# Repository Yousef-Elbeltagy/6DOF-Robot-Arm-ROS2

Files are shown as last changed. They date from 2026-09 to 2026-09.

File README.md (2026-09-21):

<div align="center">

# 6DOF Robot Arm — ROS 2

### Mechanical design → actuator sizing → FEA → URDF → simulation → control → sequence programming → autonomous jig placement









**A 6-axis robot arm developed from SolidWorks CAD into a complete ROS 2 simulation, programming, and autonomous jig-placement system.**

**[Quick Start](QUICKSTART.md) · [Documentation](docs/README.md) · [CAD Files](cad/README.md) · [Roadmap](ROADMAP.md) · [Changelog](CHANGELOG.md)**

</div>

---

## Project at a glance

| | |
|---|---|
| **Robot** | 6-DOF articulated arm + custom gripper |
| **Design target** | ~1.5 m reach, ~10 kg payload |
| **Mechanical CAD** | SolidWorks native source + STEP interoperability exports |
| **Main structure** | 6061-T6 aluminum |
| **Robot model** | URDF + STL meshes |
| **Robotics stack** | ROS 2 Humble, MoveIt 2, RViz 2, ros2_control |
| **Simulation** | Gazebo Classic 11 |
| **Control application** | Custom Python/Tkinter GUI |
| **Programming** | Saved poses, PTP/LIN sequences, blending, digital I/O, gripper actions |
| **Autonomy** | Runtime IK, dynamic TF targets, full-table jig placement |
| **Public validation** | Environment check, clean public build, and full simulation launch verified |
| **Development context** | Robotics / Mechatronics internship project |

> The final system is a **simulation-validated engineering prototype**. The physical six-axis arm was not fully commissioned during the project period because the selected integrated joint modules had a long procurement lead time.

---

## Why this project exists

Wire-harness production can depend on dedicated boards and fixed jig layouts for each product or variant. That creates slow changeovers, storage overhead, and limited flexibility when layouts change.

The concept explored here is a reusable workboard with modular jigs. Instead of rebuilding a board, the robot selects the correct jig from a source table and places it at the required target position automatically.

The long-term vision is a flexible cell where a camera reads a harness layout, identifies placement targets, and the robot configures the board automatically.

---

# Development workflow

```text
1. Mechanical architecture & CAD
             ↓
2. Torque calculation & actuator selection
             ↓
3. FEA / stiffness / manufacturability
             ↓
4. CAD → URDF conversion
             ↓
5. Gazebo + MoveIt 2 + RViz validation
             ↓
6. ros2_control integration
             ↓
7. Custom operator interface
             ↓
8. Saved poses & sequence programming
             ↓
9. Automatic jig placement
             ↓
10. Full-table autonomous simulation
```

The README follows that same order below.

---

# 1. Mechanical Design

The project started as a full mechanical robot-arm design in SolidWorks. The early work focused on the overall 6-axis architecture, cylindrical links, joint interfaces, actuator packaging, gripper integration, manufacturability, and assembly feasibility.

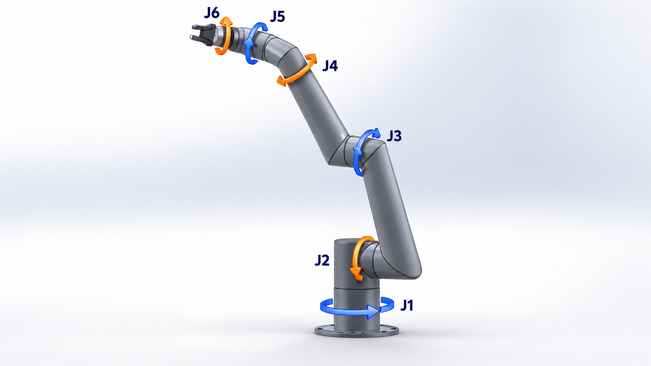
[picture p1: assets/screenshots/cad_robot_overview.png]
SolidWorks robot CAD


<table>
  <tr>
    <td align="center" width="50%">
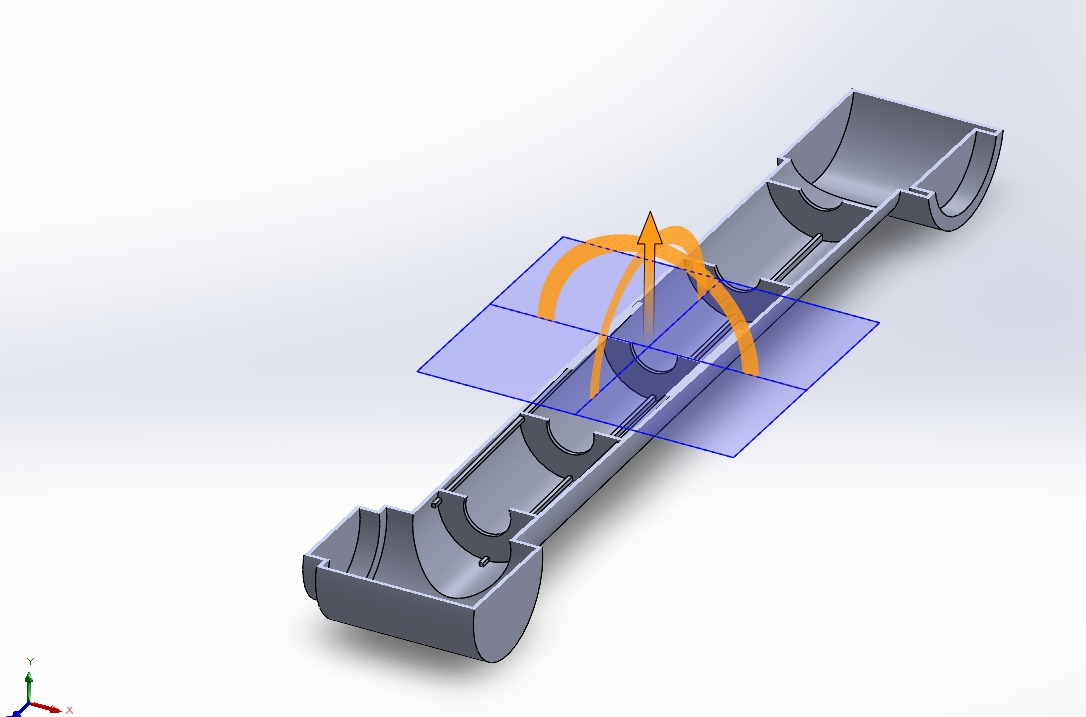
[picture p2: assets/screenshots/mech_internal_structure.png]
      <br>
      <sub><b>Early internal structural concept</b><br>Initial support/rib exploration and joint reference geometry.</sub>
    </td>
    <td align="center" width="50%">
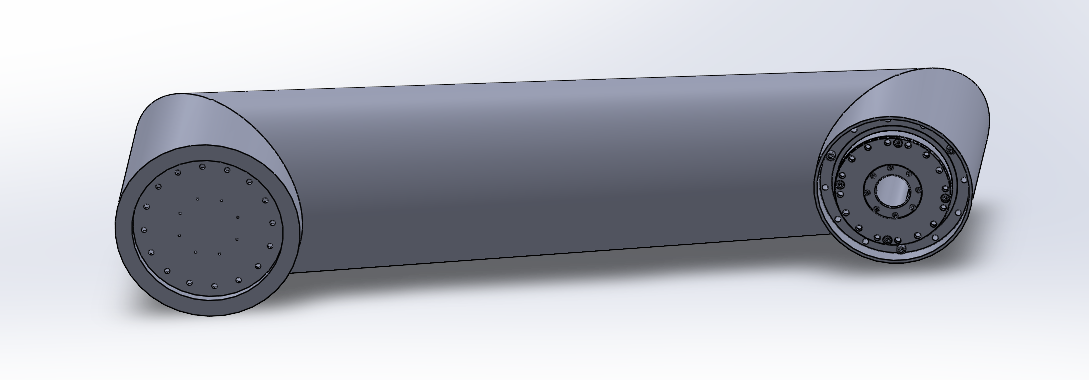
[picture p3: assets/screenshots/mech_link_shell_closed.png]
      <br>
      <sub><b>Cylindrical link shell</b><br>External link geometry and end-interface packaging.</sub>
    </td>
  </tr>
  <tr>
    <td align="center" width="50%">
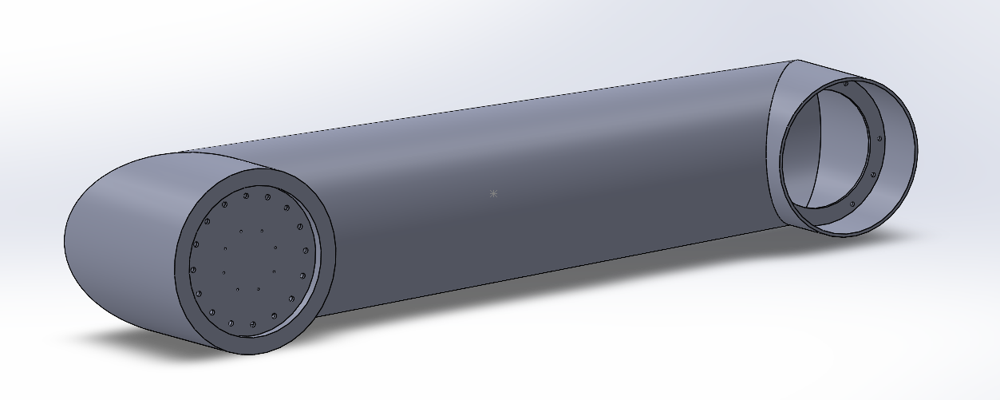
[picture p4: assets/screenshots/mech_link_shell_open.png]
      <br>
      <sub><b>Joint-side CAD view</b><br>Flange, mounting-hole, and actuator-interface development.</sub>
    </td>
    <td align="center" width="50%">
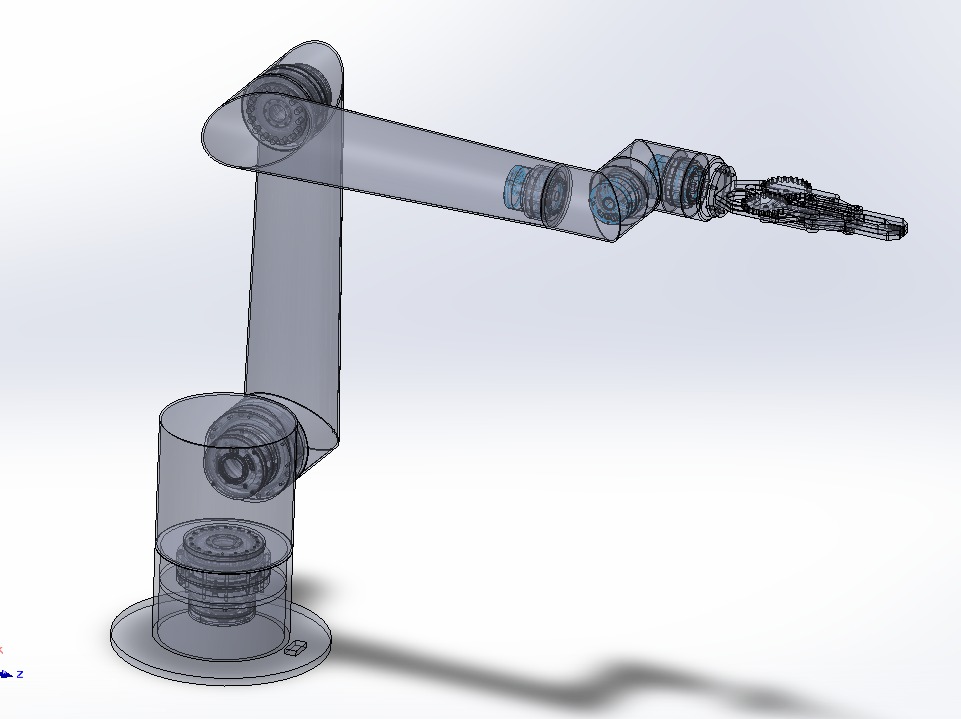
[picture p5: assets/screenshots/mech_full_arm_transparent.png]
      <br>
      <sub><b>Transparent full-arm assembly</b><br>Internal packaging of joints, drives, wrist, and gripper.</sub>
    </td>
  </tr>
</table>

### Mechanical evolution

- 6-DOF articulated architecture with cylindrical links.
- Hollow aluminum structure to reduce moving mass.
- Early internal-rib concepts were explored, then removed from the final manufacturing direction because of fabrication complexity.
- Final link strategy used simpler unribbed shells with wall thickness, geometry, local reinforcement, housings, and smooth transitions carrying the structural load.
- Custom cycloidal and planetary/belt reduction concepts were studied before integrated joint modules became the final actuator direction.

➡️ **[Mechanical design details](docs/MECHANICAL_DESIGN.md)**  
➡️ **[Native SolidWorks + STEP CAD packages](cad/README.md)**

---

# 2. Torque Calculation & Actuator Selection

The next step was determining the joint loads and selecting actuators capable of handling the arm, wrist, gripper, and payload.

### Dynamic joint torque results

| Joint | Peak torque |
|---|---:|
| J1 | 115.58 N·m |
| **J2** | **411.90 N·m** |
| J3 | 182.49 N·m |
| J4 | 35.64 N·m |
| J5 | 15.50 N·m |
| J6 | 5.10 N·m |

J2 became the governing axis because it carries the downstream links, wrist, gripper, and payload.

### Final integrated actuator concept

| Joint(s) | Module | Rated torque | Peak/start-stop torque |
|---|---|---:|---:|
| J1-J2 | TD-110-170 | 328 N·m | 702 N·m |
| J3 | TD-100-142 | 169 N·m | 411 N·m |
| J4-J6 | TD-70-90 | 50 N·m | 102 N·m |

The final concept used integrated servo/reducer modules rather than continuing with a custom gearbox for every joint. This reduced gearbox-development risk and simplified packaging around the major axes.

---

# 3. Structural Analysis & FEA

Strength alone was not enough; stiffness and local stress concentration also mattered because end-effector deflection directly affects positioning accuracy.

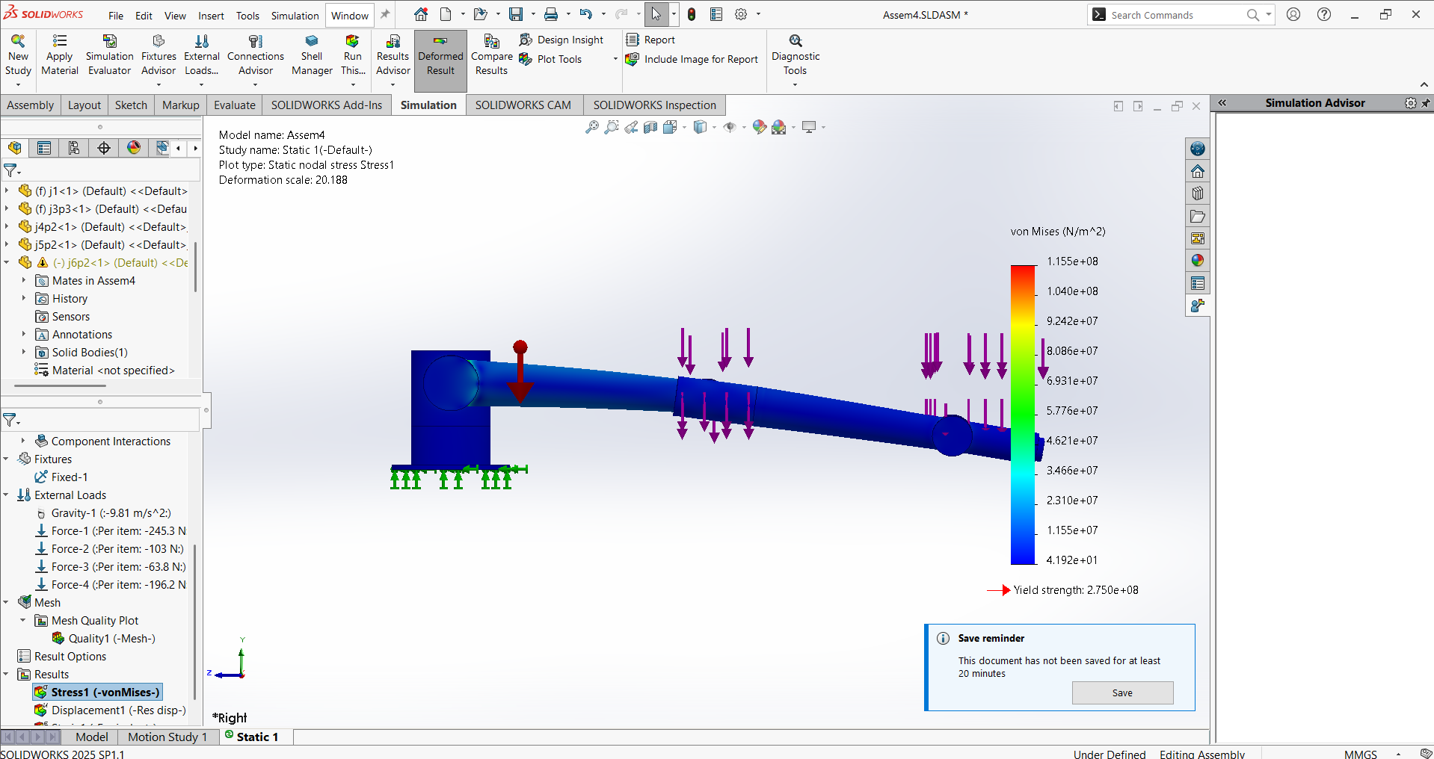
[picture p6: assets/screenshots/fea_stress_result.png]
FEA stress result


Important findings included:

- one representative study produced approximately **105 MPa** maximum stress against a 6061-T6 yield strength of approximately **275 MPa**, giving a factor of safety of about **2.6**,
- later local analysis around a J2 transition showed a much higher peak at a sharp geometric transition, identifying a stress-concentration problem rather than a uniformly overloaded link,
- global displacement studies showed that the robot could remain below yield while still being too flexible for accurate positioning,
- the long links and forearm became major stiffness drivers, leading to thickness and geometry iterations.

These results drove smoother transitions, local reinforcement, and a stronger focus on stiffness rather than only yield strength.

---

# 4. CAD → URDF → ROS 2

Once the mechanical model was stable enough, the SolidWorks assembly was prepared for ROS 2.

The export workflow included:

- parent/child link hierarchy,
- revolute joint axes,
- coordinate systems and joint origins,
- mass and center of mass,
- inertia tensors,
- motion limits,
- visual STL meshes,
- collision geometry,
- gripper mimic relationships.

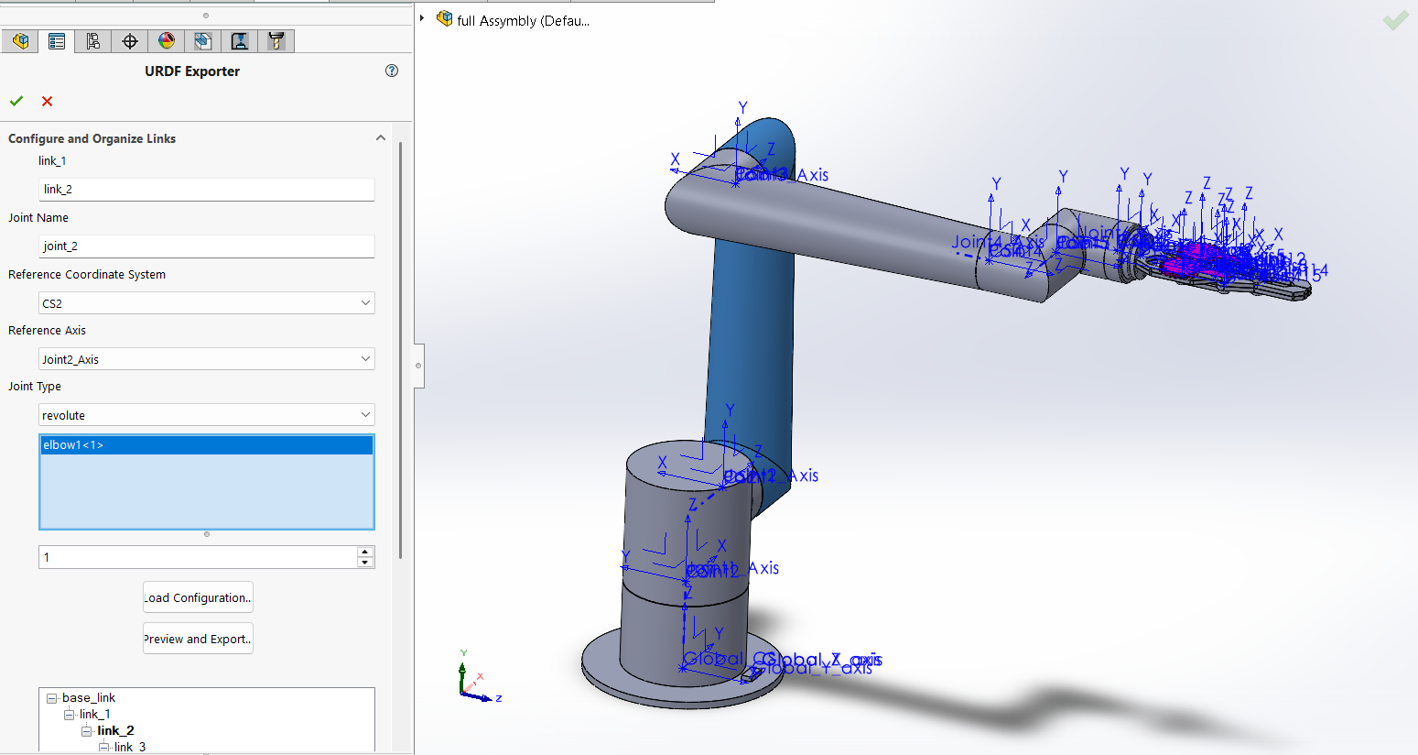
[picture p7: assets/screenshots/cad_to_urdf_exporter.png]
CAD to URDF exporter


The SolidWorks assembly pose became the zero/home reference for the URDF model, with joint names standardized as `joint_1` through `joint_6`.

---

# 5. Simulation & Motion Planning

The exported robot was then integrated into the ROS 2 simulation stack and validated before higher-level automation was added.

<table>
<tr>
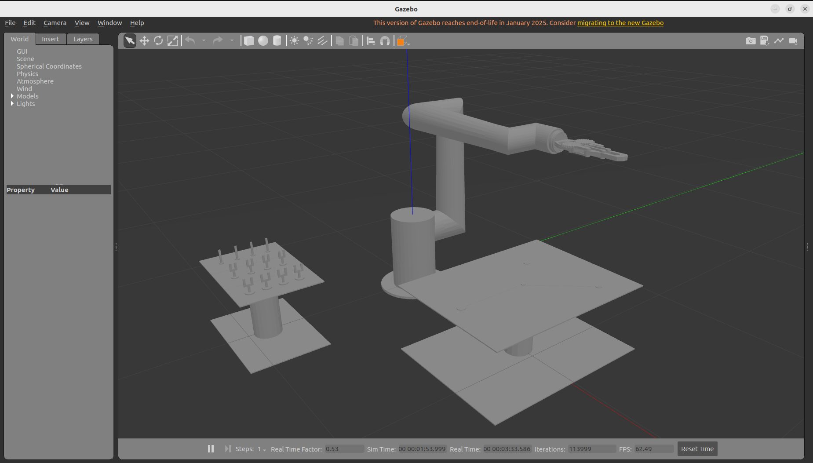
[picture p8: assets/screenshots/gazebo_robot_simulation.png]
Gazebo simulation
<td width="50%"></td>
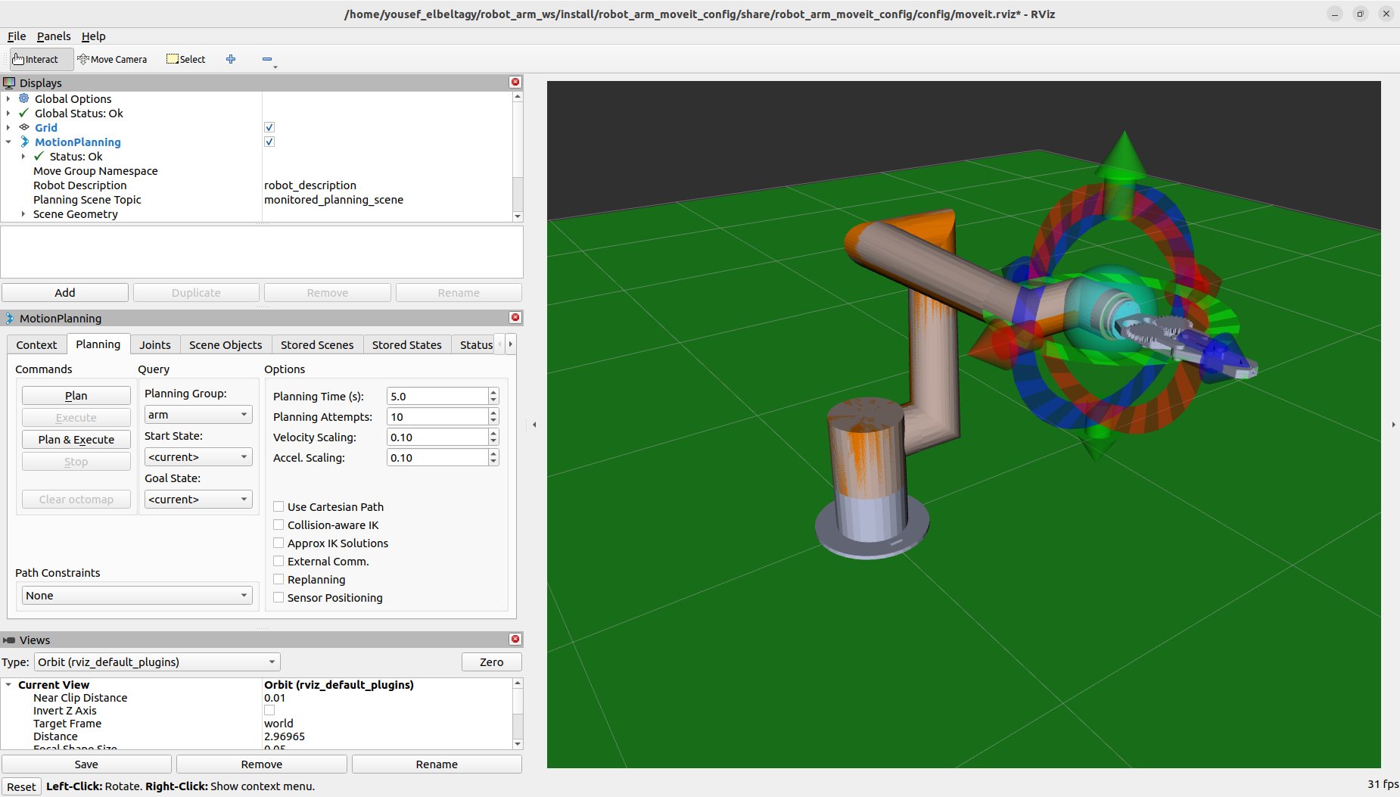
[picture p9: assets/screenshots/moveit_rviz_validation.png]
MoveIt RViz
<td width="50%"></td>
</tr>
<tr>
<td align="center"><b>Gazebo Classic 11</b></td>
<td align="center"><b>MoveIt 2 + RViz 2</b></td>
</tr>
</table>

### Simulation stack

| Layer | Technology |
|---|---|
| Operating system | Ubuntu 22.04 LTS |
| Middleware | ROS 2 Humble |
| Physics simulation | Gazebo Classic 11 |
| Motion planning | MoveIt 2 |
| Planning pipelines | OMPL + Pilz |
| Visualization | RViz 2 |
| Control | ros2_control + ros2_controllers |
| Build | colcon / ament |

MoveIt 2 handled IK, planning, collision checking, and trajectory generation. Gazebo provided the workcell physics and robot execution environment, while RViz was used to validate planning-scene and robot-state behavior.

➡️ **[Software architecture](docs/SOFTWARE_ARCHITECTURE.md)**

---

# 6. ros2_control & Robot Execution

The arm controller was integrated through `ros2_control` using trajectory actions for the six arm joints and a separate trajectory controller for the gripper.

Important execution interfaces include:

```text
/arm_controller/follow_joint_trajectory
/gripper_controller/follow_joint_trajectory
/sequence_move_group
```

This layer turned MoveIt plans into actual simulated robot motion and became the foundation for both the operator GUI and the later automatic placement system.

---

# 7. Main Operator Interface

After the robot could plan and execute reliably, a custom Python/Tkinter application was built around it.

<p align="center">
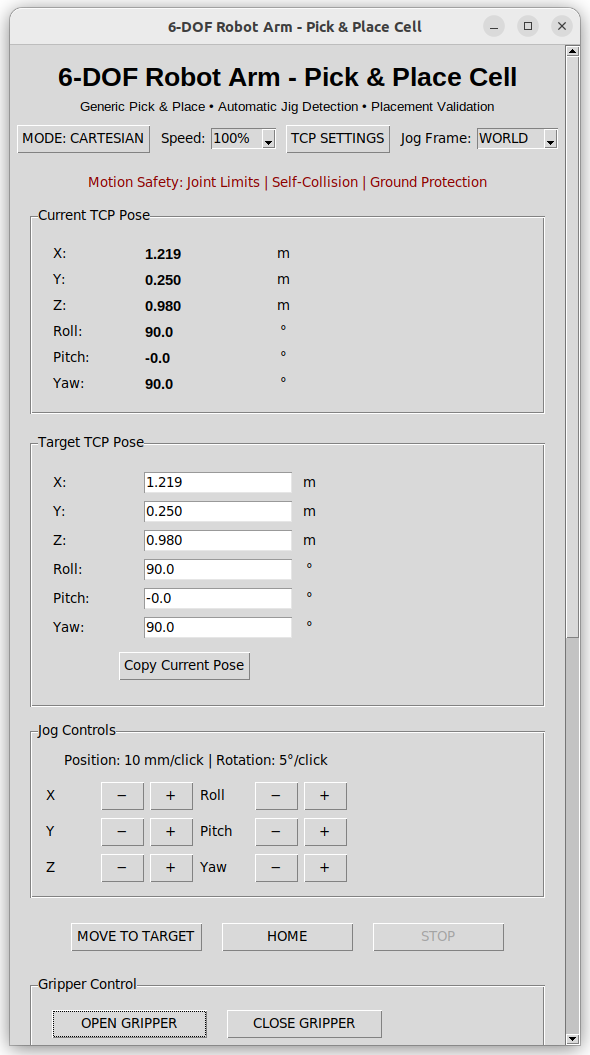
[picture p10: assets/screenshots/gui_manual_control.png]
Main Robot Control GUI
  
</p>

The interface provides:

- Cartesian X/Y/Z jogging,
- Roll/Pitch/Yaw jogging,
- joint jogging,
- speed override,
- WORLD / FLANGE / TOOL jog frames,
- configurable Tool Center Point,
- current and target TCP pose display,
- gripper open/close,
- six digital inputs,
- six digital outputs,
- saved robot poses,
- access to the Sequence Controller,
- access to Automatic Jig Placement,
- live application status.

This was the point where the project moved from a robotics stack controlled mainly through ROS tools into a usable operator-facing application.

---

# 8. Sequence Programming

The **Sequence Controller** was built after manual control and saved poses were working. It turns taught poses into ordered robot programs with motion behavior, process logic, I/O, and gripper synchronization.

<p align="center">
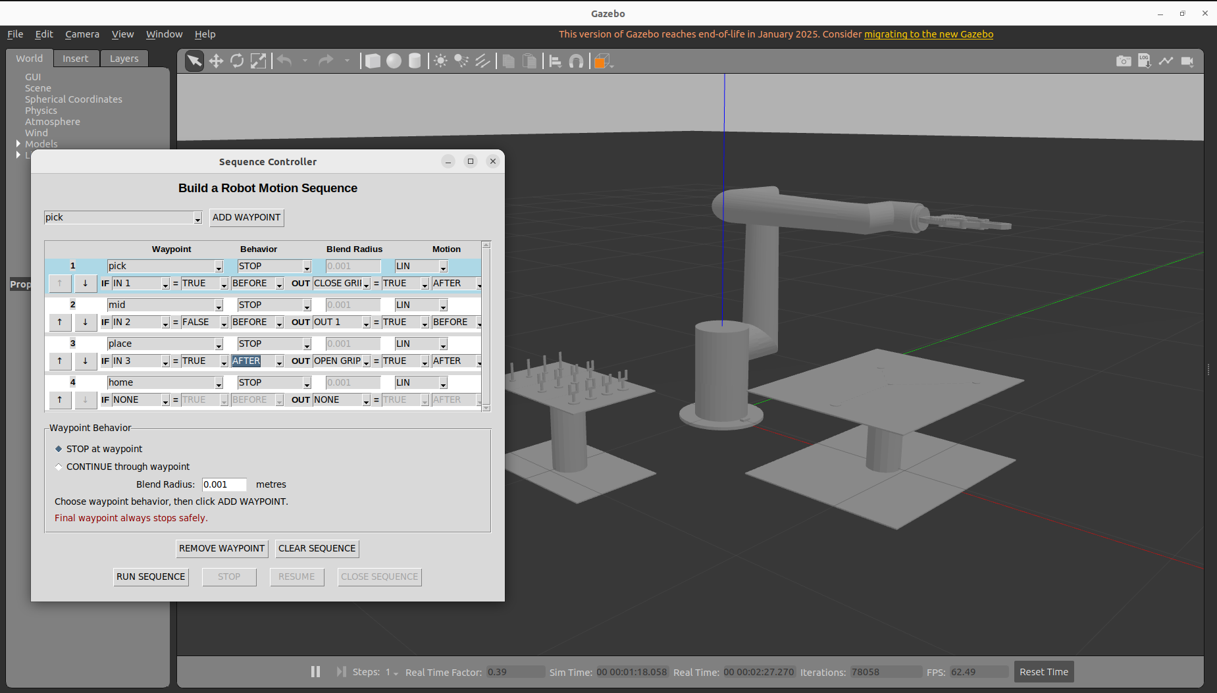
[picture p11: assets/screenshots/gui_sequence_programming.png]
Sequence Controller
  
</p>

Each program row can define:

| Sequence field | Options / behavior |
|---|---|
| **Waypoint** | Any saved robot pose |
| **Behavior** | `STOP` / `CONTINUE` |
| **Blend Radius** | Configurable transition radius |
| **Motion** | `PTP` / `LIN` |
| **Input Source** | `NONE`, `IN 1` … `IN 6` |
| **Input State** | `TRUE` / `FALSE` |
| **Input Timing** | `BEFORE` / `AFTER` |
| **Output Action** | `NONE`, `OUT 1` … `OUT 6`, `OPEN GRIPPER`, `CLOSE GRIPPER` |
| **Output State** | `TRUE` / `FALSE` where applicable |
| **Output Timing** | `BEFORE` / `AFTER` |

Example logic:

```text
IF IN 1 == TRUE BEFORE PICK → move → CLOSE GRIPPER AFTER
IF IN 2 == FALSE BEFORE MID → set OUT 1 = TRUE BEFORE
IF IN 3 == TRUE AFTER PLACE → OPEN GRIPPER AFTER
HOME → final safe stop
```

### Gripper synchronization

The arm is not allowed to continue while the gripper is still moving:

```text
arm motion segment
      ↓
stop at gripper waypoint
      ↓
send gripper FollowJointTrajectory goal
      ↓
wait for the real controller result
      ↓
continue next arm segment
```

### STOP / RESUME

STOP cancels both the active MoveIt sequence goal and the active arm-controller trajectory. RESUME retries the interrupted step from the robot's current state.

The sequence work also exposed and drove fixes for motion types being unintentionally forced to PTP, duplicate `move_group` processes, LIN/Pilz start-state constraints, stale gripper feedback, asynchronous action-result handling, and gripper synchronization.

➡️ **[Read the full Sequence Programming & Execution documentation](docs/SEQUENCE_PROGRAMMING.md)**

---

# 9. Automatic Jig Placement

The final major software layer was the autonomous jig-placement system. It combines target discovery, jig matching, runtime IK, robot motion, simulated grasping, placement validation, and repeatable full-table execution.

<p align="center">
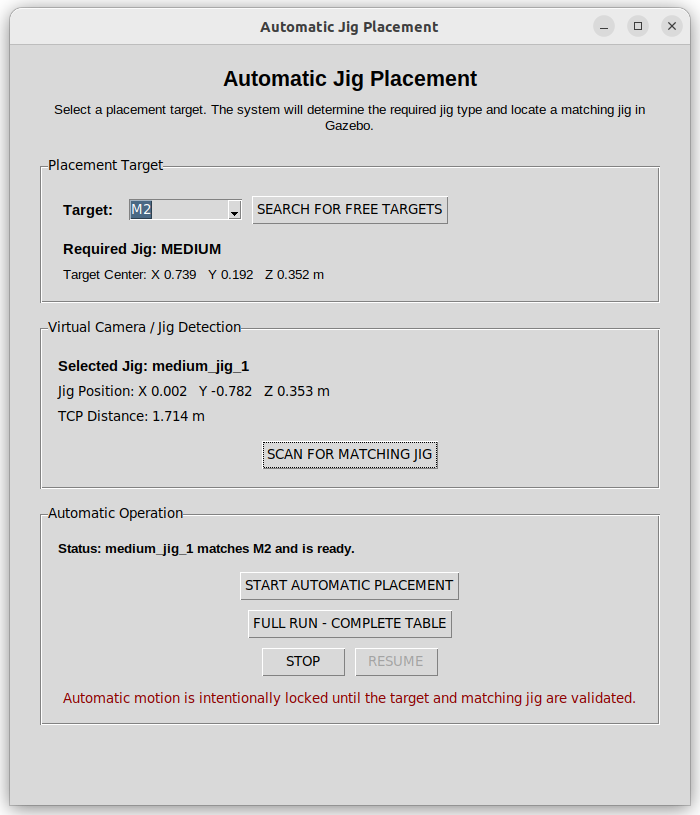
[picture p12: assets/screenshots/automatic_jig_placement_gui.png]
Automatic Jig Placement Interface
  
</p>

### Target discovery & jig matching

The interface discovers free target frames at runtime, identifies the required jig family, and searches for an unused matching jig.

```text
L1 → LARGE jig
M1 → MEDIUM jig
M2 → MEDIUM jig
S1 → SMALL jig
```

Targets are discovered from TF frame names ending in `_target_link` instead of relying only on a fixed list of coordinates.

### Runtime IK & branch selection

For each pickup and placement pose, the controller evaluates multiple IK candidates and chooses a practical branch from the current robot state:

```text
Target TCP pose
      ↓
Generate multiple IK seeds
      ↓
Call MoveIt IK
      ↓
Collect valid solutions
      ↓
Compare wrapped joint deltas
      ↓
Penalize excessive wrist motion
      ↓
Choose the lowest-motion candidate
      ↓
Execute through the PTP path
```

### Automatic execution

```text
Discover/select free target
        ↓
Infer required jig size
        ↓
Find unused matching jig
        ↓
Move above pickup
        ↓
Descend
        ↓
Close gripper + attach jig
        ↓
Lift and transfer
        ↓
Move above target
        ↓
Descend
        ↓
Open gripper + detach
        ↓
Validate placement
        ↓
Mark jig used + target occupied
        ↓
Retract and continue
```

The GUI supports both **single-placement execution** and **FULL RUN – COMPLETE TABLE**.

Two independent state trackers prevent incorrect repeated operations:

```python
placed_jig_models
filled_placement_targets
```

`placed_jig_models` prevents reuse of a jig that has already been placed. `filled_placement_targets` prevents a second jig from being sent to an occupied target.

### Stable simulated detach

Jig grasping is simulated with the IFRA LinkAttacher plugin. A difficult Gazebo stability bug was traced to detach operations being executed directly from a ROS service callback thread. The final design queues the request and performs `Joint::Detach()` from Gazebo's update thread instead.

### Immediate STOP / RESUME

STOP cancels the active MoveIt goal and active arm-controller trajectory during automatic motion. RESUME retries the interrupted automatic step from the current robot state.

### Demonstrated in simulation

- dynamic target discovery,
- automatic jig-size inference,
- unused-jig matching,
- runtime multi-seed IK,
- wrist-aware branch selection,
- simulated pickup and attachment,
- transfer and release,
- placement validation,
- jig inventory tracking,
- target occupancy tracking,
- single-target execution,
- full-table automatic execution,
- immediate STOP / RESUME.

➡️ **[Read the full Automatic Jig Placement documentation](docs/AUTOMATIC_JIG_PLACEMENT.md)**

---

# 10. Engineering Lessons & Debugging

Some of the most valuable work came from failures rather than first-pass successes:

- custom gearbox interference and manufacturability limitations,
- local stress concentrations,
- excessive structural deflection,
- duplicate MoveIt processes,
- sequence execution bugs,
- PTP/LIN handling issues,
- stale controller/GUI state,
- gripper synchronization timing,
- poor IK branches and wrist flips,
- reused-jig inventory bugs,
- Gazebo detach-thread crashes.

Each of these problems changed the design or software architecture rather than being hidden as a one-off workaround.

➡️ **[Read the engineering lessons](docs/ENGINEERING_LESSONS.md)**

---

## Repository structure

```text
6DOF-Robot-Arm-ROS2/
├── README.md
├── QUICKSTART.md
├── CHANGELOG.md
├── ROADMAP.md
├── LICENSE
├── NOTICE
├── CONTRIBUTING.md
├── src/                         # ROS 2 source packages
├── scripts/                     # dependency, build, validation and startup helpers
├── config/                      # TCP and saved-pose configuration
├── cad/
│   ├── README.md                # CAD package map and interoperability notes
│   ├── Solidworks_Cad_models/   # native SolidWorks archives
│   └── STEP_Exports/            # neutral STEP workcell/components archive
├── assets/
│   └── screenshots/             # real CAD, simulation and GUI screenshots
└── docs/                        # engineering, setup and continuation documentation
```

---

## Getting started

The validated public baseline is **Ubuntu 22.04 + ROS 2 Humble**. The repository itself is the workspace and already contains `src/`.

```bash
cd ~
git clone https://github.com/Yousef-Elbeltagy/6DOF-Robot-Arm-ROS2.git robot_arm_ws
cd ~/robot_arm_ws

bash scripts/setup_dependencies.sh
bash scripts/build_workspace.sh

cp config/robot_arm_saved_poses.json ~/robot_arm_saved_poses.json
cp config/robot_arm_tcp_config.json ~/robot_arm_tcp_config.json

bash scripts/check_system.sh
bash scripts/start_robot.sh
```

➡️ **[Quick Start](QUICKSTART.md)**  
➡️ **[Full reproduction guide](docs/REPRODUCE_PROJECT.md)**

---

## Documentation

| Document | What it covers |
|---|---|
| [Quick Start](QUICKSTART.md) | Shortest validated path from clone to launch |
| [Documentation Index](docs/README.md) | Map of all engineering and reproduction docs |
| [Reproduce Project](docs/REPRODUCE_PROJECT.md) | Clean-machine reproduction workflow |
| [Project Story](docs/PROJECT_STORY.md) | Evolution from manufacturing problem to autonomous workcell |
| [Mechanical Design](docs/MECHANICAL_DESIGN.md) | Structure, materials, torque, reducers, actuators, FEA |
| [CAD Packages](cad/README.md) | Native SolidWorks archives and STEP interoperability exports |
| [Software Architecture](docs/SOFTWARE_ARCHITECTURE.md) | ROS 2, URDF, MoveIt, Gazebo, ros2_control, GUI |
| [Sequence Programming](docs/SEQUENCE_PROGRAMMING.md) | Waypoints, PTP/LIN, blending, I/O, gripper barriers, STOP/RESUME |
| [Automatic Jig Placement](docs/AUTOMATIC_JIG_PLACEMENT.md) | Dynamic targets, runtime IK, full run, inventory and placement logic |
| [Engineering Lessons](docs/ENGINEERING_LESSONS.md) | Problems encountered and how they changed the system |
| [Results](docs/RESULTS.md) | Demonstrated capabilities and project status |
| [Gallery](docs/GALLERY.md) | Real project screenshots |
| [Setup](docs/SETUP.md) | Detailed ROS 2 environment setup |
| [Troubleshooting](docs/TROUBLESHOOTING.md) | Build/runtime diagnosis |
| [Continue Development](docs/CONTINUE_DEVELOPMENT.md) | Safe continuation path for future developers |
| [Roadmap](ROADMAP.md) | Physical integration, vision, calibration, safety and commissioning |
| [Changelog](CHANGELOG.md) | Major public repository milestones |

---

## Current status & roadmap

### Completed / validated in simulation

- [x] 6-DOF robot CAD
- [x] torque calculation and actuator selection
- [x] structural FEA / stiffness studies
- [x] gripper CAD and URDF
- [x] Gazebo simulation
- [x] MoveIt 2 planning
- [x] RViz validation
- [x] ros2_control integration
- [x] custom Python GUI
- [x] saved poses
- [x] multi-waypoint sequence programming
- [x] STOP / CONTINUE waypoint behavior
- [x] blend radius
- [x] PTP / LIN sequence selection
- [x] digital I/O sequence logic
- [x] synchronized gripper sequence actions
- [x] runtime IK
- [x] dynamic target discovery
- [x] autonomous single placement
- [x] full-table automatic execution
- [x] immediate automatic STOP / RESUME
- [x] native SolidWorks CAD publication
- [x] neutral STEP workcell/component exports
- [x] public repository environment check
- [x] public repository build validation
- [x] public Gazebo / MoveIt / RViz / GUI launch validation

### Future work

- [ ] physical actuator integration
- [ ] EtherCAT / CAN hardware interface
- [ ] real robot calibration
- [ ] camera-based target recognition
- [ ] automatic workplane calibration
- [ ] hand-guided teaching
- [ ] physical payload/stiffness validation
- [ ] industrial electrical and safety architecture
- [ ] complete cell commissioning

➡️ **[Detailed roadmap](ROADMAP.md)**

---

## Internship context & authorship

This repository documents the robot design, ROS 2 stack, simulation, control GUI, sequence-programming system, and automatic-placement engineering work developed during a broader internship project.

The internship project involved a team and supervision; this repository focuses on the technical robotics work represented here and is presented as an educational/portfolio reference rather than as a claim that every part of the wider internship project was completed by one person.

---

## Author

**Yousef El-Beltagy**  
Robotics & Mechatronics

---

<div align="center">

### CAD. ANALYZE. SIMULATE. PLAN. PROGRAM. CONTROL. AUTOMATE.

</div>

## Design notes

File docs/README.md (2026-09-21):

# Documentation Index

Use this page as the map for the project documentation.

## Start here

| Goal | Document |
|---|---|
| Get the project running quickly | [../QUICKSTART.md](../QUICKSTART.md) |
| Reproduce the project from a clean machine | [REPRODUCE_PROJECT.md](REPRODUCE_PROJECT.md) |
| Continue development from the current state | [CONTINUE_DEVELOPMENT.md](CONTINUE_DEVELOPMENT.md) |
| Diagnose runtime/build problems | [TROUBLESHOOTING.md](TROUBLESHOOTING.md) |
| Inspect native/neutral CAD | [../cad/README.md](../cad/README.md) |
| See planned next engineering phases | [../ROADMAP.md](../ROADMAP.md) |
| Review public project milestones | [../CHANGELOG.md](../CHANGELOG.md) |
| Contribute changes | [../CONTRIBUTING.md](../CONTRIBUTING.md) |

## Engineering documentation

| Topic | Document |
|---|---|
| Project evolution | [PROJECT_STORY.md](PROJECT_STORY.md) |
| Mechanical design | [MECHANICAL_DESIGN.md](MECHANICAL_DESIGN.md) |
| Major components / actuator BOM | [BOM.md](BOM.md) |
| ROS 2 / MoveIt / Gazebo architecture | [SOFTWARE_ARCHITECTURE.md](SOFTWARE_ARCHITECTURE.md) |
| Sequence Controller | [SEQUENCE_PROGRAMMING.md](SEQUENCE_PROGRAMMING.md) |
| Automatic jig placement | [AUTOMATIC_JIG_PLACEMENT.md](AUTOMATIC_JIG_PLACEMENT.md) |
| Engineering lessons | [ENGINEERING_LESSONS.md](ENGINEERING_LESSONS.md) |
| Demonstrated results and current status | [RESULTS.md](RESULTS.md) |
| Screenshots | [GALLERY.md](GALLERY.md) |
| Setup details | [SETUP.md](SETUP.md) |

## Mechanical source packages

The `cad/` directory contains:

- native SolidWorks archives for the robot/gripper, jigs, and workcell tables,
- a neutral STEP archive containing the complete workcell and separate component STEP exports.

See [../cad/README.md](../cad/README.md) before modifying or redistributing mechanical source files.

## Recommended reading order for a new developer

```text
QUICKSTART
    ↓
REPRODUCE_PROJECT
    ↓
SOFTWARE_ARCHITECTURE
    ↓
SEQUENCE_PROGRAMMING
    ↓
AUTOMATIC_JIG_PLACEMENT
    ↓
CONTINUE_DEVELOPMENT
    ↓
TROUBLESHOOTING as needed
```

For mechanical continuation, also read `MECHANICAL_DESIGN.md`, `BOM.md`, and `../cad/README.md` before changing link geometry or actuator selection.

## Status language

The public repository represents a **simulation-validated engineering prototype**. Do not describe the project as a fully commissioned or certified industrial/collaborative robot unless future physical testing and safety validation support that claim.

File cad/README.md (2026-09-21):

# CAD Models

This directory contains the mechanical CAD packages used for the 6-DOF robot-arm project, including both the original SolidWorks files and neutral STEP exports for interoperability.

## Available CAD archives

| Archive | Contents | Approx. size |
|---|---|---:|
| `Solidworks_Cad_models/full_Cobot_Solidworks_Cad.zip` | Full 6-DOF robot arm and gripper SolidWorks CAD package | 32.7 MB |
| `Solidworks_Cad_models/Cobot_Jigs_Solidworks_Cad.zip` | Jig CAD models used by the automatic placement workcell | 0.9 MB |
| `Solidworks_Cad_models/Pick_Table_Solidworks_Cad.zip` | Pick/placement table and target-related SolidWorks CAD package | 1.2 MB |
| `STEP_Exports/Complete_Robot_Workcell_STEP_Components.zip` | Neutral STEP export package containing the complete robot workcell assembly together with separate STEP component files | 22.0 MB |

## Which format should I use?

Use the **SolidWorks archives** when you want the original editable design files and native assembly relationships.

Use the **STEP export archive** when you want to inspect, measure, reuse, or import the geometry in another CAD package without requiring SolidWorks.

The STEP archive contains:

- the complete robot/workcell STEP assembly,
- the 6-DOF robot and gripper geometry,
- workcell table geometry,
- target and jig geometry,
- separate STEP files for the exported assembly components.

## Relationship to the ROS 2 model

The CAD models are the mechanical source geometry behind the robot and workcell that were later converted into ROS 2 / Gazebo assets.

The corresponding software models are located under `src/`, including:

- `robot_arm_with_gripper_urdf`
- `table_harness_urdf_v3`
- `pick_table_urdf`
- `large_jig_urdf`
- `medium_jig_urdf`
- `small_jig_urdf`

The robot assembly was prepared in SolidWorks with joint axes, reference geometry, mass properties, and link relationships before export to URDF and STL meshes for ROS 2.

## Mechanical design status

The published CAD represents the engineering prototype developed during the project. The system was validated extensively in simulation, but the complete physical six-axis robot was not fully commissioned during the project period because the selected integrated actuator modules had a long procurement lead time.

Important mechanical design notes:

- 6-DOF articulated robot architecture
- approximately 1.5 m design reach
- approximately 10 kg payload design target
- 6061-T6 aluminum as the main structural material
- integrated servo/reducer joint modules selected as the final actuator direction
- early internal-rib concepts were investigated, but the final manufacturing direction used simpler unribbed cylindrical shells with local reinforcement and appropriate wall thickness
- custom gripper integrated into the final robot assembly

## Opening the files

### SolidWorks

Extract the relevant ZIP archive before opening its assemblies or parts. Keep all referenced files from an archive together after extraction so SolidWorks can resolve assembly references correctly.

### STEP

Extract `STEP_Exports/Complete_Robot_Workcell_STEP_Components.zip`, then open either the complete workcell STEP assembly or the individual component STEP files in any CAD package with STEP support.

## Notes for contributors

Please do not commit SolidWorks temporary/lock files such as `~$*` or backup files. Large handover archives, private company documents, supplier quotations, and internal project backups are intentionally excluded from this public repository.

For the mechanical design background, see [`../docs/MECHANICAL_DESIGN.md`](../docs/MECHANICAL_DESIGN.md).

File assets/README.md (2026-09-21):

# Screenshot Assets

These images were extracted from the project's own presentation material and originate from real project screenshots/CAD/simulation captures supplied during development.

They are intended for the public GitHub project page.

Included:
- SolidWorks robot CAD
- CAD/URDF exporter view
- FEA result
- Gazebo robot simulation
- MoveIt/RViz validation
- Python GUI/manual-control walkthrough
- Sequence programming walkthrough
- Automatic jig-placement GUI workflow

No image-generation artwork is included in this folder.

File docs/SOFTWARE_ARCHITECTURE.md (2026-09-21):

# Software Architecture

The project combines a CAD-derived robot model with ROS 2 motion planning, physics simulation, trajectory control and a custom operator interface.

## Platform

```text
Ubuntu 22.04 LTS
ROS 2 Humble
Gazebo Classic 11
MoveIt 2
RViz 2
ros2_control
ros2_controllers
OMPL
Pilz Industrial Motion Planner
Python 3 / Tkinter
```

## Data flow

```text
SolidWorks CAD
      ↓
URDF + STL meshes
      ↓
ROS 2 robot description
      ↓
+-----------------------------+
|                             |
↓                             ↓
Gazebo Classic             MoveIt 2
physics / joints           planning / IK
|                             |
+-------------+---------------+
              ↓
          ros2_control
              ↓
      trajectory controllers
              ↓
      custom Python GUI
```

## Main ROS packages

The development workspace contains packages for the robot, workcell and application logic, including:

```text
robot_arm_with_gripper_urdf
robot_arm_moveit_config
robot_arm_python
pymoveit2
table_harness_urdf_v3
pick_table_urdf
large_jig_urdf
medium_jig_urdf
small_jig_urdf
IFRA_LinkAttacher
```

## URDF model

The robot model contains six revolute arm joints plus the full gripper hierarchy.

The CAD-to-URDF workflow preserves:

- parent/child link hierarchy
- joint origin and axis
- joint limits
- mass
- center of mass
- inertia tensor
- visual meshes
- collision meshes
- gripper mimic relationships

## MoveIt 2

MoveIt is used for:

- inverse kinematics
- collision-aware planning
- joint-limit checking
- trajectory generation
- planning scene visualization
- sequence execution

The main planning group is:

```text
arm
```

The project uses OMPL and Pilz planning pipelines. PTP is the known-good motion mode used by the automatic placement workflow.

## ros2_control

The simulated arm is controlled through a FollowJointTrajectory controller for J1-J6, with a separate trajectory controller for the gripper.

Important actions include:

```text
/arm_controller/follow_joint_trajectory
/gripper_controller/follow_joint_trajectory
/sequence_move_group
```

## Custom operator GUI

The Python/Tkinter controller evolved into a full robot operator interface.

It supports:

- Cartesian X/Y/Z jogging
- Roll/Pitch/Yaw jogging
- J1-J6 joint jogging
- speed override
- WORLD / FLANGE / TOOL jog frames
- TCP configuration
- saved poses
- HOME
- STOP / RESUME
- gripper open/close
- sequence programming
- PTP / LIN row selection
- STOP / CONTINUE waypoint behavior
- blend radius
- digital I/O
- automatic jig placement

## Tool Center Point

The working TCP used by the controller is approximately:

```text
[0, 0, 0.4193463143, 0, 0, 0]
```

This is intentionally different from the shorter `link_6 -> gripper_base` transform. The GUI performs the TCP/flange conversion mathematically when generating motion targets.

## Sequence controller

The sequence system is designed to feel closer to an industrial robot programming workflow than a basic list of poses.

Each row can contain:

- saved waypoint
- STOP / CONTINUE behavior
- blend radius
- PTP / LIN selection
- digital input condition
- digital output action
- gripper actions

Gripper actions act as execution barriers: arm motion stops, the gripper trajectory completes, and only then does the next arm segment begin.

## Immediate STOP / RESUME

A major behavior improvement was making STOP interrupt an active automatic movement rather than waiting for the current trajectory to finish.

The implementation cancels both the MoveIt sequence goal and the active arm-controller trajectory. RESUME then retries the interrupted automatic step from the robot's current state.

## Gazebo grasping

The simulated pick-and-place uses IFRA LinkAttacher services to attach and detach jig models.

A native Gazebo crash was traced to detach operations being performed from the ROS service callback thread. The plugin was modified so that detach requests are queued and the actual `Joint::Detach()` occurs inside Gazebo's update thread.

This was one of the most important simulation-stability fixes in the project.

## Development philosophy

The project was debugged using an evidence-first workflow:

1. reproduce the failure
2. inspect ROS/Gazebo logs
3. isolate the failing layer
4. change one behavior at a time
5. rebuild
6. cold-restart when runtime state matters
7. create checkpoints after stable milestones

That workflow was especially important because failures could originate from the GUI, MoveIt, controller timing, TF, Gazebo physics or plugin threading.

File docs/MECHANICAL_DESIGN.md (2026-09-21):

# Mechanical Design

This project started as a mechanical robot-arm design problem before it became a ROS 2 software project.

## Design target

The main concept was a 6-axis articulated arm for a flexible wire-harness manufacturing cell.

- Target reach: approximately **1.5 m**
- Target payload: approximately **10 kg**
- Architecture: 6 revolute joints
- Main structural material: **Aluminum 6061-T6**
- Manufacturing goal: geometry that could realistically be produced and assembled

## Joint architecture

| Joint | Main role |
|---|---|
| J1 | Base rotation |
| J2 | Shoulder elevation |
| J3 | Elbow positioning |
| J4 | Wrist orientation |
| J5 | Wrist orientation |
| J6 | Tool/flange orientation |

J2 became the governing mechanical joint because it carries the payload together with the mass of the downstream links, wrist, gripper and actuators.

## Link design evolution

The arm went through several iterations. Early designs explored thicker cylindrical shells and internal ribs. Later iterations moved toward lighter hollow links, with wall thickness and local joint-housing geometry carrying the structural load.

The final manufacturing direction avoided internal ribs after fabrication feedback showed that the ribbed concept would be unnecessarily difficult to manufacture.

Instead, stiffness improvements were focused on:

- increasing local wall thickness where needed
- larger diameters where practical
- smoother transitions between links and joint housings
- larger fillets at high-stress transitions
- stronger local actuator mounting regions

## Material selection

6061-T6 aluminum was selected for the main moving links because of its combination of:

- low density
- good strength-to-weight ratio
- corrosion resistance
- machinability
- practical availability

Other materials considered during development included 7075-T6, stainless steel and alloy steels for localized high-stress parts such as shafts and pins.

## Torque model

The final dynamic peak torque values used in the engineering presentation were approximately:

| Joint | Dynamic peak torque |
|---|---:|
| J1 | 115.58 N·m |
| J2 | **411.90 N·m** |
| J3 | 182.49 N·m |
| J4 | 35.64 N·m |
| J5 | 15.50 N·m |
| J6 | 5.10 N·m |

This made J2 the governing axis for actuator sizing.

## Gearbox research

Several drivetrain concepts were investigated before the final actuator selection.

### Custom cycloidal reducers

A custom cycloidal gearbox was explored because precision robot reducers were difficult to source locally.

The work included:

- single- and multi-stage ratio studies
- dual cycloidal discs
- eccentric shaft design
- roller/pin geometry
- interference checking
- bearing-pocket sizing
- material selection and heat-treatment considerations

The concept was ultimately not selected because the machining precision, backlash control, heat treatment and development schedule created too much project risk.

### Planetary + timing belt

A planetary gearbox with optional timing-belt pre-reduction was also studied. This provided more realistic local manufacturability but still added packaging and compliance complexity.

### Final integrated joint modules

The final concept moved to integrated robotic joint modules containing the motor, encoder, brake and reducer in one unit.

| Joints | Module | Rated torque | Peak/start-stop torque |
|---|---|---:|---:|
| J1-J2 | TD-110-170 | 328 N·m | 702 N·m |
| J3 | TD-100-142 | 169 N·m | 411 N·m |
| J4-J6 | TD-70-90 | 50 N·m | 102 N·m |

This dramatically simplified the mechanical integration compared with designing six custom reducer assemblies.

## FEA lessons

Structural analysis showed two distinct engineering challenges:

1. **Local stress concentration** around joint transitions, especially near J2.
2. **Global deflection** of the long links.

One study showed a high local peak around the J2 transition, while stress dropped substantially a short distance away. That indicated a geometry-driven stress concentration rather than uniform tube failure.

Another displacement study showed end-effector deflection on the order of a few centimetres under the assumed loading case, indicating that stiffness was a more important issue than simply increasing material strength.

The main design lessons were therefore:

- do not optimize only for yield stress
- examine displacement and stiffness at the TCP
- use smooth load paths
- avoid sharp housing transitions
- increase local thickness only where it improves the load path

## CAD-to-robot-model workflow

SolidWorks was used to define:

- link geometry
- joint axes
- reference coordinate systems
- mass properties
- centers of mass
- inertias
- visual/collision meshes

These definitions were then carried into the URDF model used by ROS 2, Gazebo and MoveIt.

## Status

The mechanical design reached a simulation-ready and actuator-integrated CAD stage. The complete physical robot was not commissioned during the internship/project period because the selected integrated joint modules had a long procurement lead time.

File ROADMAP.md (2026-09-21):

# Roadmap

The current repository is a **simulation-validated engineering prototype**. This roadmap separates demonstrated software capability from future physical-system work.

## Current validated baseline

- 6-DOF robot and custom gripper CAD
- torque sizing and actuator selection
- structural FEA and stiffness studies
- URDF / STL model generation
- Gazebo Classic 11 simulation
- MoveIt 2 + RViz planning and validation
- ros2_control arm and gripper execution
- manual Cartesian and joint jogging
- saved poses and TCP handling
- industrial-style sequence programming
- synchronized gripper actions
- digital I/O logic
- PTP / LIN sequence selection
- runtime IK with multi-seed branch selection
- dynamic target discovery
- automatic jig pickup and placement
- placement and inventory validation
- full-table automatic execution
- immediate STOP / RESUME
- native SolidWorks CAD archives
- neutral STEP workcell/component exports
- clean public build and launch validation on Ubuntu 22.04 / ROS 2 Humble

## Next engineering phase

### 1. Physical actuator integration

- install the selected integrated joint modules,
- define final mechanical mounting and cable routing,
- validate brake behavior,
- map real joint feedback and commands into ros2_control,
- implement repeatable startup and shutdown procedures.

Tracked in GitHub issue #1.

### 2. Industrial communication

- integrate EtherCAT and/or CAN interfaces supported by the selected actuators,
- define hardware abstraction and fault handling,
- validate command rate, feedback timing, and emergency-stop behavior.

### 3. Robot calibration

- establish joint-zero references,
- calibrate kinematic parameters,
- validate TCP position/orientation,
- characterize backlash, repeatability, and payload-dependent deflection.

### 4. Vision and automatic workplane setup

- select and calibrate a camera,
- detect workboard / harness-layout targets,
- estimate the workplane pose,
- transform detected targets into the robot frame,
- feed approved targets into the existing automatic-placement pipeline.

Tracked in GitHub issue #2.

### 5. Physical performance validation

- payload testing,
- structural-deflection measurements,
- repeatability testing,
- cycle-time measurement,
- long-duration reliability testing.

### 6. Industrial safety and commissioning

- electrical architecture,
- safety-rated stop design,
- guarding / collaborative-operation assessment,
- risk assessment,
- production commissioning.

## Reproduction quality

A clean-machine reproduction test remains useful for confirming that no implicit development-machine dependency is missing from the public instructions. See GitHub issue #3.

## Mechanical-source completeness

Native SolidWorks archives and neutral STEP exports are now included. Further additions should be limited to genuinely useful manufacturing drawings or updated revisions rather than historical CAD backups. See GitHub issue #4 for the original CAD-publication task.

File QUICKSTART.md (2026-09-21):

# Quick Start

For the complete walkthrough, use [docs/REPRODUCE_PROJECT.md](docs/REPRODUCE_PROJECT.md). This page is the shortest validated path from a clean Ubuntu 22.04 machine to the simulated robot.

## Supported baseline

```text
Ubuntu 22.04 LTS
ROS 2 Humble
Gazebo Classic 11
MoveIt 2
RViz 2
ros2_control / ros2_controllers
Python 3 / Tkinter
colcon / ament
```

## 1. Clone the repository as the workspace

The repository already contains its ROS packages under `src/`, so clone the repository itself as `~/robot_arm_ws`:

```bash
cd ~
git clone https://github.com/Yousef-Elbeltagy/6DOF-Robot-Arm-ROS2.git robot_arm_ws
cd ~/robot_arm_ws
```

Do **not** clone the whole repository into `~/robot_arm_ws/src`; that would create a nested `src/src` layout.

## 2. Install dependencies

After installing ROS 2 Humble, Gazebo Classic, MoveIt 2, ros2_control, and the development tools listed in [docs/REPRODUCE_PROJECT.md](docs/REPRODUCE_PROJECT.md), run:

```bash
cd ~/robot_arm_ws
bash scripts/setup_dependencies.sh
```

## 3. Build

```bash
cd ~/robot_arm_ws
bash scripts/build_workspace.sh
```

A successful build should finish all project packages without errors.

## 4. Restore GUI configuration

The GUI reads the saved-pose and TCP configuration from the user's home directory:

```bash
cp ~/robot_arm_ws/config/robot_arm_saved_poses.json ~/robot_arm_saved_poses.json
cp ~/robot_arm_ws/config/robot_arm_tcp_config.json ~/robot_arm_tcp_config.json
```

## 5. Verify the environment

```bash
cd ~/robot_arm_ws
bash scripts/check_system.sh
```

The validated project machine reported all checks passing before the public launch test.

## 6. Start the complete simulation

```bash
cd ~/robot_arm_ws
bash scripts/start_robot.sh
```

The launcher brings up Gazebo Classic, MoveIt 2, RViz 2, the arm and gripper controllers, and the custom robot GUI.

## 7. First checks after launch

Verify that:

- the robot appears correctly in Gazebo and RViz,
- `/move_group` is running,
- the arm and gripper controllers are active,
- the GUI opens and reports a connected robot,
- small jogs and gripper commands execute correctly.

Then test a saved pose, a short Sequence Controller program, and the Automatic Jig Placement interface.

## Where to go next

- Full reproduction guide: [docs/REPRODUCE_PROJECT.md](docs/REPRODUCE_PROJECT.md)
- Setup details: [docs/SETUP.md](docs/SETUP.md)
- Continue development: [docs/CONTINUE_DEVELOPMENT.md](docs/CONTINUE_DEVELOPMENT.md)
- Troubleshooting: [docs/TROUBLESHOOTING.md](docs/TROUBLESHOOTING.md)
- Software architecture: [docs/SOFTWARE_ARCHITECTURE.md](docs/SOFTWARE_ARCHITECTURE.md)
- Sequence programming: [docs/SEQUENCE_PROGRAMMING.md](docs/SEQUENCE_PROGRAMMING.md)
- Automatic jig placement: [docs/AUTOMATIC_JIG_PLACEMENT.md](docs/AUTOMATIC_JIG_PLACEMENT.md)
- Native and neutral CAD: [cad/README.md](cad/README.md)
- Contributing: [CONTRIBUTING.md](CONTRIBUTING.md)

## Project status

This repository reproduces the **simulation-validated engineering prototype**. Physical actuator integration, calibration, machine safety, certification, and production commissioning remain future work.

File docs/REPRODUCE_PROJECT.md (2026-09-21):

# Reproduce the Project

This guide is for someone who wants to clone the repository, build the ROS 2 workspace, launch the simulation, and reach the same software baseline used during development.

## Supported baseline

- Ubuntu 22.04 LTS
- ROS 2 Humble
- Gazebo Classic 11
- MoveIt 2
- RViz 2
- ros2_control / ros2_controllers
- OMPL
- Pilz Industrial Motion Planner
- Python 3 + Tkinter
- colcon / ament

The project was developed against Gazebo Classic rather than modern Gz Sim.

## 1. Install ROS 2 and development tools

Follow the official ROS 2 Humble installation procedure for Ubuntu 22.04, then install the main packages:

```bash
sudo apt update
sudo apt install -y \
  ros-humble-desktop \
  build-essential \
  cmake \
  git \
  python3-pip \
  python3-tk \
  python3-yaml \
  python3-rosdep \
  python3-colcon-common-extensions \
  python3-vcstool \
  ros-humble-ros2-control \
  ros-humble-ros2-controllers \
  gazebo \
  ros-humble-gazebo-ros-pkgs \
  ros-humble-gazebo-ros2-control \
  ros-humble-moveit \
  ros-humble-moveit-planners-ompl \
  ros-humble-pilz-industrial-motion-planner
```

Initialize rosdep if needed:

```bash
sudo rosdep init
rosdep update
```

If `rosdep init` reports that it was already initialized, continue with `rosdep update`.

## 2. Clone the repository as the workspace

The repository root already contains `src/`, `scripts/`, `config/`, and the project documentation. Clone the repository itself as the workspace:

```bash
cd ~
git clone https://github.com/Yousef-Elbeltagy/6DOF-Robot-Arm-ROS2.git robot_arm_ws
cd ~/robot_arm_ws
```

The resulting layout should look like:

```text
~/robot_arm_ws/
├── src/
├── scripts/
├── config/
├── docs/
└── README.md
```

Do not clone the complete repository inside `~/robot_arm_ws/src`, because that creates a nested `src/src` layout and breaks the documented helper-script paths.

## 3. Install package dependencies

Recommended:

```bash
cd ~/robot_arm_ws
bash scripts/setup_dependencies.sh
```

Equivalent rosdep command:

```bash
source /opt/ros/humble/setup.bash
cd ~/robot_arm_ws
rosdep install --from-paths src --ignore-src -r -y --rosdistro humble
```

`warehouse_ros_mongo` is intentionally not required by this repository. It is optional MoveIt warehouse functionality and is not needed for the normal planning, simulation, sequence, or jig-placement workflows documented here.

## 4. Build

Recommended:

```bash
cd ~/robot_arm_ws
bash scripts/build_workspace.sh
```

Equivalent manual build:

```bash
cd ~/robot_arm_ws
source /opt/ros/humble/setup.bash
colcon build --symlink-install
source install/setup.bash
```

The public repository has been validated by building all project packages from its own `src/` tree.

## 5. Restore runtime configuration

The GUI expects these files in the user's home directory:

```text
~/robot_arm_saved_poses.json
~/robot_arm_tcp_config.json
```

Copy the repository versions:

```bash
cp ~/robot_arm_ws/config/robot_arm_saved_poses.json ~/robot_arm_saved_poses.json
cp ~/robot_arm_ws/config/robot_arm_tcp_config.json ~/robot_arm_tcp_config.json
```

The validated TCP translation is approximately:

```text
[0, 0, 0.4193463143]
```

Do not replace that value with the shorter `link_6 -> gripper_base` offset; they represent different things.

## 6. Check the environment

Run:

```bash
cd ~/robot_arm_ws
bash scripts/check_system.sh
```

Fix any reported missing dependency before launching the full system. On the validated development machine, the public environment check completed with all checks passing.

## 7. Launch the project

The convenience launcher starts Gazebo, waits for both arm and gripper controllers, starts MoveIt, opens RViz, then launches the Tkinter GUI:

```bash
cd ~/robot_arm_ws
bash scripts/start_robot.sh
```

Expected major components:

```text
Gazebo Classic
MoveIt / move_group
RViz 2
arm_controller
gripper_controller
Robot GUI
```

The public repository was also launch-tested after a clean build: Gazebo, MoveIt, RViz, the GUI, robot model, and controllers all started correctly.

## 8. Verify a successful launch

Controllers:

```bash
ros2 control list_controllers
```

Expected active controllers include the six-axis arm trajectory controller and the gripper trajectory controller.

MoveIt:

```bash
ros2 node list | grep move_group
```

There should normally be one active `/move_group` instance.

Sequence action:

```bash
ros2 action info /sequence_move_group
```

Arm trajectory action:

```bash
ros2 action info /arm_controller/follow_joint_trajectory
```

Gripper trajectory action:

```bash
ros2 action info /gripper_controller/follow_joint_trajectory
```

## 9. First functional test

Use the GUI in this order:

1. Confirm the status reports that the robot is connected.
2. Test a very small Cartesian jog.
3. Test gripper open / close.
4. Load one saved pose and move to it.
5. Open the Sequence Controller and run a short two-waypoint sequence.
6. Open Automatic Jig Placement, search for a free target, scan for a matching jig, and validate the displayed target/jig information before starting motion.

## 10. Repository packages

Important packages include:

```text
robot_arm_with_gripper_urdf
robot_arm_moveit_config
robot_arm_python
pymoveit2
table_harness_urdf_v3
pick_table_urdf
large_jig_urdf
medium_jig_urdf
small_jig_urdf
IFRA_LinkAttacher
```

## 11. Mechanical source files

The public `cad/` directory contains both native SolidWorks archives and neutral STEP exports. See [../cad/README.md](../cad/README.md) for the CAD package map and interoperability notes.

## 12. What is reproduced

This repository reproduces the simulation and control prototype, including:

- six-axis robot + gripper URDF,
- Gazebo workcell,
- MoveIt planning,
- ros2_control execution,
- manual GUI control,
- saved poses,
- sequence programming,
- digital I/O logic,
- runtime IK,
- automatic jig selection and placement,
- simulated attach/detach,
- full-table automation logic.

It does not reproduce a commissioned physical industrial robot. Hardware integration, calibration, safety engineering, certification, and production commissioning remain future work.

## 13. If something fails

See [TROUBLESHOOTING.md](TROUBLESHOOTING.md) before changing coordinates, IK logic, controller timing, or attach/detach behavior.

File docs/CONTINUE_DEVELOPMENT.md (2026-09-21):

# Continue Development

This document is for the next developer who wants to continue the project from the current simulation-validated state rather than reconstructing its history from commits.

## Current validated state

The repository contains a working ROS 2 Humble simulation/control stack for a 6-DOF arm with gripper and a wire-harness jig-placement workcell.

Validated in simulation:

- 6-DOF arm URDF and meshes
- gripper integration
- Gazebo Classic workcell
- ros2_control arm and gripper trajectory execution
- MoveIt 2 planning
- RViz validation
- Cartesian and joint jogging
- saved robot poses
- configurable TCP
- sequence programming
- STOP / CONTINUE waypoint behavior
- blend radius
- PTP / LIN selection
- digital input/output logic
- synchronized gripper actions
- runtime IK
- dynamic placement-target discovery
- unused-jig inventory tracking
- target occupancy tracking
- single automatic placement
- full-table automatic execution
- immediate STOP / RESUME

## Important files

```text
src/robot_arm_python/robot_arm_python/robot_gui.py
    Main GUI, manual control, sequence logic, runtime IK and automatic placement.

src/robot_arm_with_gripper_urdf/
    Robot/gripper model, Gazebo launch files and workcell-related simulation assets.

src/robot_arm_moveit_config/
    MoveIt configuration, planning pipelines and controllers.

src/IFRA_LinkAttacher/
    Modified link-attacher implementation used for simulated jig grasp/release.

config/robot_arm_saved_poses.json
    Portable copy of saved poses.

config/robot_arm_tcp_config.json
    Portable copy of the validated TCP configuration.

scripts/start_robot.sh
    Main system launcher.

scripts/start_robot_DIAGNOSTIC_GAZEBO.sh
    Diagnostic startup path for Gazebo-related failures.
```

## Runtime invariants worth preserving

### TCP

The validated TCP offset is approximately:

```text
[0, 0, 0.4193463143, 0, 0, 0]
```

Do not substitute the `link_6 -> gripper_base` transform as the TCP.

### Controller names

Arm:

```text
/arm_controller/follow_joint_trajectory
```

Gripper:

```text
/gripper_controller/follow_joint_trajectory
```

MoveIt sequence action:

```text
/sequence_move_group
```

### Automatic-placement state

Two independent sets matter:

```python
placed_jig_models
filled_placement_targets
```

The first prevents reusing a physical jig. The second prevents placing into an already occupied target. Do not merge them.

## Automatic jig placement architecture

The high-level flow is:

```text
Discover free target TFs
        ↓
Infer jig family from target name
        ↓
Find unused matching jig
        ↓
Generate runtime IK candidates
        ↓
Score candidate joint motion
        ↓
Move to pickup
        ↓
Close + attach
        ↓
Transfer
        ↓
Open + detach
        ↓
Validate
        ↓
Update inventory + occupancy
        ↓
Continue
```

Targets are discovered dynamically from TF frame names ending in `_target_link`.

## Runtime IK

The automatic controller intentionally uses multiple IK seeds because the first valid mathematical solution may contain unnecessary wrist rotation.

The candidate score is based on wrapped joint deltas from the current state, with additional weight on wrist motion. This should remain generic; avoid target-specific joint hard-coding unless a clearly documented exception is unavoidable.

## Sequence Controller

Each programmed row can contain:

- saved waypoint
- STOP / CONTINUE
- blend radius
- PTP / LIN
- input source
- TRUE / FALSE input state
- BEFORE / AFTER condition timing
- output action
- output state
- BEFORE / AFTER output timing
- OPEN GRIPPER / CLOSE GRIPPER

Gripper actions use an execution barrier: arm motion reaches the appropriate step, the gripper trajectory is sent, the actual action result is awaited, then arm execution continues.

Do not reintroduce asynchronous gripper execution or duplicate gripper commands through the generic output path.

## Immediate STOP / RESUME

STOP is intended to cancel both:

```text
active MoveIt sequence goal
active arm FollowJointTrajectory goal
```

RESUME retries the interrupted step from the robot's current state.

If changing execution logic, verify that STOP still interrupts actual robot motion rather than merely setting a software flag.

## Gazebo detach stability

A critical stability fix exists in the modified IFRA LinkAttacher implementation.

Unsafe historical pattern:

```text
ROS service callback -> Joint::Detach()
```

Stable architecture:

```text
ROS service callback
    ↓
queue detach request
    ↓
Gazebo OnUpdate()
    ↓
Joint::Detach()
```

Do not casually replace the modified implementation with a stock copy without porting this behavior.

## Recommended next software work

1. Add repeatable automated smoke tests.
2. Improve launch orchestration so fewer external terminal windows are required.
3. Add parameterization for workcell geometry and target naming.
4. Improve LIN reliability and start-state handling.
5. Add structured logging instead of relying only on console text.
6. Add camera/perception integration for target extraction.
7. Add calibration helpers for a real workplane.
8. Separate simulation-specific attach/detach logic from future hardware gripper logic.

## Recommended next hardware work

1. Integrate the selected actuators.
2. Implement EtherCAT or CAN hardware interfaces.
3. Validate motor brakes and startup behavior.
4. Perform joint-zero calibration.
5. Validate payload and structural deflection physically.
6. Measure TCP repeatability.
7. Implement electrical safety architecture.
8. Add guarding / safety-rated functions as required by the final application.
9. Commission the complete cell.

## Modifying the robot geometry

If the mechanical geometry changes:

1. Update the CAD assembly.
2. Re-export affected meshes.
3. Update URDF joint origins / axes / inertias.
4. Rebuild the workspace.
5. Validate the TF tree.
6. Validate collision geometry in RViz.
7. Test small motions before large Cartesian moves.
8. Re-check the TCP.
9. Re-check saved poses; old Cartesian poses may no longer be valid.

## Adding a new target

Prefer the existing dynamic naming model:

```text
<target_id>_target_link
```

Choose a target prefix that maps clearly to a jig family, then ensure the target TF is published and that the corresponding jig model can be discovered by the matching logic.

After adding a target, test:

- target appears in free-target discovery
- correct jig family is inferred
- used jigs are excluded
- placement IK has a reasonable branch
- target becomes occupied only after validated placement

## Adding a new jig family

Update all layers consistently:

1. jig model / URDF
2. spawn or workcell configuration
3. naming convention
4. GUI family inference
5. matching-jig search
6. pickup validation
7. attach/detach logic if link names differ

## Before a risky change

Create a Git checkpoint first:

```bash
git status
git add -A
git commit -m "Checkpoint before <change>"
```

Then change one subsystem at a time and verify the previous known-good behavior before continuing.

## Project status statement

This repository should be described as a simulation-validated engineering prototype. It is not a physically commissioned or safety-certified collaborative robot.

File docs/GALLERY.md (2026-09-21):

# Project Gallery

All images below are **real project CAD, analysis, simulation, and GUI captures** from the development work. AI-generated robot artwork is intentionally excluded.

---

## 1. Mechanical CAD

### Complete 6-DOF robot model

SolidWorks robot CAD

### Structural / internal design view

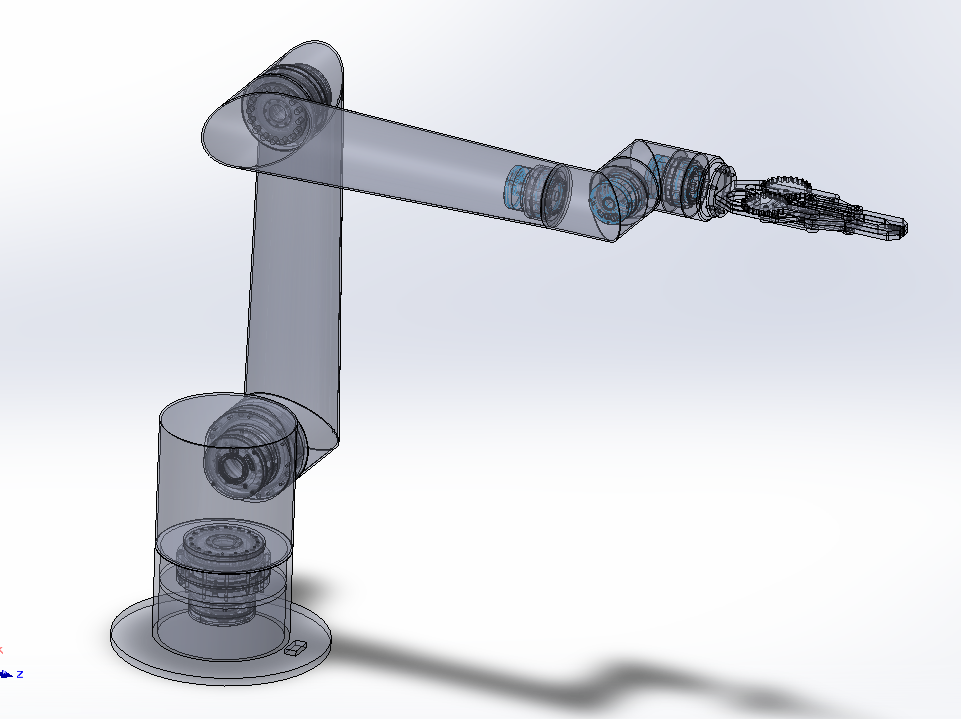
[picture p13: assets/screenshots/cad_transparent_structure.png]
Transparent CAD structure


The mechanical design evolved through several iterations covering link geometry, joint packaging, manufacturability, actuator integration, and stiffness.

---

## 2. Structural analysis

FEA stress result

FEA was used not only to check stress, but also to understand stiffness, local stress concentrations, and end-effector deflection.

---

## 3. CAD to URDF workflow

CAD to URDF exporter

The SolidWorks assembly was converted into a ROS-compatible robot model with link hierarchy, revolute joints, coordinate systems, inertial properties, STL meshes, and collision geometry.

---

## 4. Gazebo workcell simulation

Gazebo robot and jig-placement workcell

The current Gazebo Classic 11 capture shows the complete simulated robot, custom gripper, source jig table, and reusable workboard used by the pick-and-place / jig-placement application.

---

## 5. MoveIt 2 and RViz

MoveIt and RViz

MoveIt 2 handled inverse kinematics, planning, collision checking, and trajectory generation while RViz was used to validate planning-scene and robot-state behavior.

---

## 6. Custom operator interface

Main robot control GUI

The Python/Tkinter operator application combines:

- Cartesian X/Y/Z and Roll/Pitch/Yaw jogging,
- target motion and HOME,
- gripper open/close,
- six digital inputs,
- six digital outputs,
- saved robot poses,
- the Sequence Controller,
- Automatic Jig Placement,
- live application status.

---

# 7. Sequence

Sequence programming is a dedicated project feature, not just a small GUI utility. It lets the operator build ordered robot routines from saved poses and combine motion with process logic.

### Sequence entry point in the main GUI

Main GUI with Sequence Controller entry point

The operator teaches or saves robot poses in the main application and then opens **SEQUENCE CONTROLLER** to assemble them into a robot program.

### Sequence Controller next to the simulated robot

Sequence Controller with Gazebo

Each sequence row can define:

- a saved **Waypoint**,
- `STOP` or `CONTINUE` behavior,
- a **Blend Radius**,
- `PTP` or `LIN` motion,
- an input source `NONE` / `IN 1` … `IN 6`,
- an expected input state `TRUE` / `FALSE`,
- input timing `BEFORE` / `AFTER`,
- an output `NONE` / `OUT 1` … `OUT 6`,
- `OPEN GRIPPER` / `CLOSE GRIPPER`,
- output state `TRUE` / `FALSE`,
- output timing `BEFORE` / `AFTER`.

The sequence interface also provides **RUN SEQUENCE**, **STOP**, **RESUME**, waypoint removal, and sequence clearing.

A key implementation detail is the **gripper synchronization barrier**: arm motion stops at the relevant waypoint, the gripper trajectory is sent, the software waits for the real controller result, and only then does the next arm segment begin. This prevents asynchronous arm/gripper overlap.

The sequence work also drove fixes for mixed PTP/LIN execution, duplicate `move_group` processes, Pilz linear-planning constraints, stale gripper state, action-result handling, and true mid-motion STOP/RESUME behavior.

➡️ **[Read the full Sequence Programming & Execution documentation](SEQUENCE_PROGRAMMING.md)**

---

## 8. Automatic jig placement

Automatic jig placement GUI

The automatic-placement layer combines target discovery, jig selection, runtime IK, simulated gripping, attach/detach, occupied-target tracking, validation, full-table execution, and immediate STOP/RESUME.

---

## Project progression

```text
Mechanical CAD
    ↓
FEA / torque / actuator sizing
    ↓
URDF + meshes
    ↓
Gazebo workcell simulation
    ↓
MoveIt 2 + RViz
    ↓
Custom GUI
    ↓
Saved poses
    ↓
Sequence programming + I/O + gripper synchronization
    ↓
Automatic jig placement
    ↓
Full-table autonomous simulation
```

---

[← Back to main README](../README.md)

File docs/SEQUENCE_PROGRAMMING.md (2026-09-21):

# Sequence Programming & Execution

The **Sequence Controller** is a dedicated robot-programming layer in this project. It turns taught/saved poses into ordered motion programs and combines robot motion with process logic, digital I/O, gripper actions, blending, and execution control.

This was one of the most important software milestones between manual jogging and the later automatic jig-placement system.

---

## Sequence entry point in the main robot GUI

The main operator application provides jogging, gripper control, digital I/O, saved poses, sequence programming, and automatic jig placement from one interface.

Main robot control GUI

From the **Saved Robot Poses** area, the operator can teach/store reusable poses and open the **SEQUENCE CONTROLLER** to build a program from them.

---

## Sequence Controller running with the simulated robot

The sequence window is a separate programming interface while Gazebo continues to show the robot and workcell.

Sequence Controller with Gazebo robot

The example capture shows a four-step program — `pick`, `mid`, `place`, and `home` — with motion type, stop behavior, blend radius, input conditions, output/gripper actions, and timing all configured row by row.

---

## What can be programmed in each row

| Sequence field | Available behavior | Purpose |
|---|---|---|
| **Waypoint** | Any saved robot pose | Defines the target pose for that program step |
| **Behavior** | `STOP` / `CONTINUE` | Stop precisely at the waypoint or continue through an eligible blended transition |
| **Blend Radius** | e.g. `0.001 m` | Controls the continuous transition around a waypoint when blending is allowed |
| **Motion** | `PTP` / `LIN` | Selects point-to-point or linear Cartesian motion |
| **Input Source** | `NONE`, `IN 1` … `IN 6` | Selects the digital input used as a process condition |
| **Input State** | `TRUE` / `FALSE` | Defines the state that the selected input must satisfy |
| **Input Timing** | `BEFORE` / `AFTER` | Checks the condition before or after the waypoint operation |
| **Output Action** | `NONE`, `OUT 1` … `OUT 6`, `OPEN GRIPPER`, `CLOSE GRIPPER` | Commands a digital output or the gripper |
| **Output State** | `TRUE` / `FALSE` | Defines the output state where applicable |
| **Output Timing** | `BEFORE` / `AFTER` | Executes the output/gripper action before or after waypoint motion |

The final waypoint is treated as a safe stopping point rather than being blended through the end of the program.

---

## Example process logic

A sequence can express logic such as:

```text
1. PICK
   IF IN 1 == TRUE BEFORE
   move with LIN
   CLOSE GRIPPER AFTER

2. MID
   IF IN 2 == FALSE BEFORE
   move through the intermediate pose
   set OUT 1 = TRUE BEFORE

3. PLACE
   IF IN 3 == TRUE AFTER
   move to the placement pose
   OPEN GRIPPER AFTER

4. HOME
   return to the home pose
   stop safely at the final waypoint
```

This makes the table more than a pose list: it becomes a small industrial-style robot/process program.

---

## STOP vs CONTINUE

### STOP

The robot reaches the programmed waypoint and stops before the next operation. This is useful for:

- gripping and releasing,
- process synchronization,
- digital I/O changes,
- inspection points,
- any step where the next action must wait for the current one to finish.

### CONTINUE

The sequence can continue through an eligible waypoint using the configured blend radius. This reduces unnecessary stop-start motion and follows the same general programming idea used by industrial robot controllers for approximated/blended paths.

---

## PTP and LIN motion

### PTP — Point-to-Point

PTP plans a joint-space move toward the target pose. It became the most reliable and thoroughly validated sequence mode in this project and is intentionally used for the final automatic jig-placement workflow.

### LIN — Linear Cartesian motion

LIN was implemented so the operator can request straight Cartesian tool motion between programmed points. It required substantially more debugging because Pilz planning, IK, acceleration limits, and the robot start state all affect whether a linear path can be accepted.

An important bug found during development was that an older mixed-sequence path could overwrite the operator's selected motion types and force all rows to PTP. The execution logic was changed so the real per-row `PTP` / `LIN` selection is preserved.

---

## Digital inputs: BEFORE / AFTER + TRUE / FALSE

The sequence controller supports six logical digital inputs:

```text
IN 1  IN 2  IN 3  IN 4  IN 5  IN 6
```

For each programmed input condition the operator selects:

```text
expected state: TRUE or FALSE
check timing:   BEFORE or AFTER
```

Examples:

```text
IF IN 1 == TRUE BEFORE PICK
IF IN 2 == FALSE BEFORE MID
IF IN 3 == TRUE AFTER PLACE
```

This provides the basis for synchronizing the robot with sensors, fixtures, PLC-style process states, or other cell conditions.

---

## Digital outputs

Six logical outputs are available:

```text
OUT 1  OUT 2  OUT 3  OUT 4  OUT 5  OUT 6
```

An output can be commanded `TRUE` or `FALSE`, and its action can occur `BEFORE` or `AFTER` the associated waypoint. That allows the robot program to coordinate motion with process equipment rather than treating motion and I/O as separate systems.

---

## Gripper actions inside a sequence

The output-action field also supports:

```text
OPEN GRIPPER
CLOSE GRIPPER
```

These are not treated like ordinary fire-and-forget outputs. The arm and gripper must be synchronized so that the next arm move cannot begin while the gripper is still opening or closing.

The final execution model uses a **gripper barrier**:

```text
arm motion segment
      ↓
stop at gripper waypoint
      ↓
send gripper FollowJointTrajectory goal
      ↓
wait for the real controller result
      ↓
verify completion
      ↓
continue the next arm segment
```

The generic output handler also ignores gripper outputs when the dedicated gripper barrier is handling them, preventing duplicate open/close commands.

---

## Why cached gripper state was removed

An older implementation used a cached GUI value similar to:

```python
self.current_gripper_position
```

That state could lag behind the actual Gazebo/controller state. The more robust design waits for the real `FollowJointTrajectory` action result and trusts successful controller completion (`error_code == 0`) before continuing.

This was an important ROS 2 control lesson: **goal acceptance is not the same as motion completion**.

---

## RUN, STOP, and RESUME

The Sequence Controller provides:

- **RUN SEQUENCE** — starts the programmed routine,
- **STOP** — interrupts active execution,
- **RESUME** — continues/retries the interrupted step from the robot's current state,
- **REMOVE WAYPOINT** — removes an unwanted program row,
- **CLEAR SEQUENCE** — resets the programmed sequence.

The STOP path was developed beyond a simple GUI flag. It cancels the active MoveIt sequence goal and the active arm-controller `FollowJointTrajectory` goal so the simulated robot can actually stop during motion. RESUME then restarts the interrupted operation from the current state rather than assuming the previous trajectory completed.

---

## Execution architecture

```text
Saved robot poses
      ↓
Sequence Controller GUI
      ↓
Waypoint + behavior + blend + motion
      ↓
Input conditions + output/gripper actions
      ↓
Segment around STOP / I/O / gripper barriers
      ↓
MoveIt 2 / Pilz planning
      ↓
/sequence_move_group
      ↓
/arm_controller/follow_joint_trajectory
      ↓
ros2_control
      ↓
Gazebo robot
```

The gripper uses its own trajectory controller:

```text
/gripper_controller/follow_joint_trajectory
```

---

## Important sequence bugs and engineering lessons

The system required substantial iteration because failures could occur at the GUI, planner, action, controller, or simulator layer. Key issues solved during development included:

- mixed-sequence logic unintentionally forcing rows to PTP,
- an intermediate `segment_end` segmentation bug,
- duplicate `move_group` processes causing confusing action behavior,
- LIN/Pilz acceleration and start-state constraints,
- IK/start-state failures that appeared only on some linear moves,
- stale cached gripper state,
- distinguishing goal acceptance from actual execution completion,
- preventing duplicate gripper commands,
- forcing synchronization barriers around open/close actions,
- implementing actual mid-motion STOP and useful RESUME behavior.

---

## Relationship to automatic jig placement

The sequence controller and automatic jig placement are separate application layers, but the sequence work laid much of the control foundation:

```text
manual jogging
      ↓
saved poses
      ↓
sequence programming
      ↓
PTP/LIN + blending
      ↓
I/O + gripper synchronization
      ↓
robust action handling and cancellation
      ↓
automatic jig-placement state machine
```

The automatic placement workflow later added runtime IK, dynamic TF target discovery, jig inventory, attach/detach logic, occupied-target tracking, validation, and full-table execution.

---

## Why this feature matters

The Sequence Controller demonstrates the integration of:

- reusable taught robot poses,
- industrial-style waypoint programming,
- PTP and LIN motion selection,
- STOP/CONTINUE behavior,
- path blending,
- digital input conditions,
- TRUE/FALSE process logic,
- BEFORE/AFTER event timing,
- digital outputs,
- synchronized gripper operations,
- MoveIt 2 sequence execution,
- ros2_control trajectory actions,
- cancellation and STOP/RESUME behavior,
- debugging across asynchronous ROS 2 components.

For this project, sequence programming is the point where the robot moved from **"a simulated arm that can be jogged"** to **"a programmable robotic system that can execute an ordered process."**

---

[← Back to main README](../README.md)

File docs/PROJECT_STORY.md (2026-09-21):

# Project Story

## From a manufacturing problem to a complete robotics stack

This project was developed during a robotics/mechatronics internship project around a real wire-harness manufacturing challenge.

The underlying problem was product changeover. Traditional harness assembly can rely on dedicated boards and fixed jig layouts. New variants create extra board fabrication, storage and reconfiguration work.

The project explored a different idea: use a reusable workboard and let a robot place the required modular jigs automatically.

That simple application idea grew into a full robotics development workflow.

## Phase 1 — Mechanical concept

The first challenge was not ROS or software. It was designing a robot that could physically reach the work area and carry a meaningful payload.

The arm evolved through:

- multiple link geometries
- material studies
- ribbed and unribbed structures
- torque calculations
- joint-housing design
- FEA
- custom reducer research
- final integrated actuator selection

The target concept became a six-axis arm with roughly 1.5 m reach and a 10 kg payload target.

## Phase 2 — Gearbox and actuator decisions

Precision reducers were difficult to source locally, so the project initially investigated custom cycloidal gearboxes and later planetary/belt concepts.

The gearbox work was useful because it exposed the manufacturing difficulty hidden behind high-ratio robot joints: backlash, heat treatment, bearing stiffness, surface finish and tolerance control.

The final design moved to integrated servo-reducer joint modules, allowing the project to progress from component research to full-system integration.

## Phase 3 — CAD becomes a digital robot

The SolidWorks assembly was prepared for URDF export using explicit coordinate systems and revolute-joint axes.

The digital model then carried the robot into the ROS ecosystem:

```text
SolidWorks
  -> URDF + meshes
  -> ROS 2
  -> Gazebo
  -> MoveIt
  -> RViz
```

This stage connected mechanical engineering decisions directly to kinematics, collision geometry and simulation.

## Phase 4 — Motion planning and control

After the robot model was stable in Gazebo, MoveIt 2 and ros2_control were integrated.

The project progressed from simple joint motion to:

- Cartesian jogging
- joint jogging
- speed override
- TCP handling
- multiple jogging frames
- saved poses
- sequence programming
- PTP and LIN experimentation
- digital I/O behavior
- gripper trajectory control

The controller eventually became a custom Python/Tkinter operator interface rather than a collection of terminal commands.

## Phase 5 — Autonomous jig placement

The most advanced software phase was automatic jig placement.

The GUI learned to:

- discover free targets from TF
- infer required jig size from target naming
- scan for a compatible jig
- reject already-used jig models
- compute runtime IK
- choose a good IK branch
- pick and attach the jig
- move to the target
- release/detach
- validate placement
- mark target occupancy
- continue through the full table

At that point, the project was no longer just a robot model. It was a simulated manufacturing application.

## Phase 6 — Reliability engineering

Some of the most useful work came from failures.

Examples include:

- duplicate MoveIt servers
- stale TCP data during pickup
- gripper timeouts caused by slow simulation time
- poor IK branches causing wrist flips
- reusing jigs that had already been placed
- unsafe Gazebo detach behavior causing native simulator crashes
- STOP behavior that initially did not interrupt motion immediately

Each failure forced the architecture to become more robust.

## What the project demonstrates

The project combines several disciplines that are often taught separately:

- mechanical design
- FEA
- actuator sizing
- kinematics
- robot description formats
- ROS 2
- motion planning
- simulation
- controller integration
- GUI development
- autonomous state logic
- debugging across a distributed robotics stack

## Scope and honesty

The project reached a strong simulation-validated stage. It did **not** reach complete physical commissioning of the six-axis arm during the internship period because the selected joint modules had a long procurement lead time.

That distinction is important: the repository represents a real engineering development project and a functioning simulated robot application, not a certified production robot.

## Personal contribution

This repository documents my robotics/mechatronics work on the project and the technical system I helped develop during the internship. The broader internship project involved a project team and supervision, while this repository focuses specifically on the robot design, ROS 2 stack, simulation, GUI and automatic-placement engineering work represented here.

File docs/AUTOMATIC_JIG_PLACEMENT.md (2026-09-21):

# Automatic Jig Placement

The automatic jig-placement system is the most application-specific part of the project. It turns the robot from a manual simulation into a complete pick-and-place workflow for a reconfigurable wire-harness workcell.

## Problem being solved

Traditional wire-harness boards are often dedicated to a product or variant. That makes changeover slow, storage-heavy and inflexible.

The project concept uses a reusable workboard with modular jigs. The robot selects the required jig from a source table and places it at the correct target on the board.

## Workcell model

The simulated workcell contains:

- 6-DOF robot arm
- gripper
- source jig table
- large / medium / small jig models
- target placement table
- named target TF frames

Example targets:

```text
L1
M1
M2
S1
```

The target prefix represents the required jig family:

```text
L -> large jig
M -> medium jig
S -> small jig
```

## Dynamic target discovery

The target list is not intended to be hard-coded.

The GUI inspects TF frames at runtime and searches for frame names ending in:

```text
_target_link
```

It then converts those frame names into operator-friendly target IDs and excludes targets that have already been filled.

This means the GUI can adapt to the workcell state instead of relying only on a fixed list of coordinates.

## Jig inventory tracking

A separate set tracks jig models that have already been used:

```python
self.placed_jig_models
```

This was added after a real simulation bug: once M1 had been filled, the nearest medium jig to M2 could accidentally be the jig already placed at M1.

The fix was to keep an explicit used-jig inventory and ignore placed models during future scans.

Target occupancy is tracked separately using:

```python
self.filled_placement_targets
```

These two states solve different problems:

- `placed_jig_models` prevents reusing a physical jig
- `filled_placement_targets` prevents filling the same target twice

## Automatic sequence

A typical placement cycle is:

```text
1. Discover/select target
2. Infer required jig size
3. Scan for matching unused jig
4. Open gripper
5. Move above pickup
6. Descend to pickup
7. Close gripper and attach jig
8. Lift
9. Move above target
10. Descend to placement
11. Open gripper and detach jig
12. Validate placement
13. Mark jig used
14. Mark target occupied
15. Retract
16. Continue to next target
```

Known working height conventions during the simulation were approximately:

```text
pickup Z         0.370 m
placement Z      0.371 m
approach/retract 0.500 m
```

The safe travel height was increased during development after inter-target motion passed too close to already placed jigs.

## Runtime inverse kinematics

The automatic routine does not depend on one pre-recorded joint pose for every target.

Instead it uses MoveIt's IK service to compute a joint solution for the requested TCP pose.

The runtime IK process:

1. accepts a desired TCP pose
2. converts it to the `link_6` flange pose
3. calls MoveIt IK for planning group `arm`
4. tries multiple seed configurations
5. evaluates valid solutions
6. chooses the solution requiring the most reasonable wrapped joint motion
7. executes through the known-good PTP path

## Closest IK branch selection

One of the most visible problems during development was a valid IK solution that caused unnecessarily large wrist rotations.

Rather than hard-code one target, the controller evaluates multiple IK candidates and scores their wrapped joint differences from the current robot state.

The score gives additional weight to the wrist joints, which reduces undesirable wrist flips while keeping the solution generic.

A generic target-azimuth seed was also added to improve branch selection for targets such as S1.

## Simulated grasping

Jig grasping is simulated through the IFRA LinkAttacher plugin.

The robot closes its gripper and calls the attach service for the nearest valid jig within the pickup range.

During release, the detach operation is queued and executed in the Gazebo update thread. This threading change was necessary to prevent native `gzserver` crashes during repeated automatic runs.

## Full-table run

The GUI supports a full-run mode that repeatedly:

- searches for remaining free targets
- identifies the required jig type
- finds an unused matching jig
- executes placement
- validates completion
- updates occupancy/inventory
- continues automatically

This allowed the simulated workcell to complete the available L1/M1/M2/S1 placement sequence without manual reselection between targets.

## STOP / RESUME

The automatic controller supports immediate interruption.

STOP cancels the active MoveIt goal and arm-controller trajectory instead of waiting for the movement to finish.

RESUME then retries the interrupted automatic step from the current robot state.

This was particularly useful during development and demonstrations because the complete routine could be safely interrupted without restarting the whole run.

## Honest project status

The automatic workcell was validated in simulation. It demonstrates the control architecture and application logic, but it is not a physically commissioned production cell.

A real implementation would still require actuator/hardware integration, calibration, real gripping validation, electrical safety, machine safety and full commissioning.

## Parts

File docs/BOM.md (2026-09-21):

# Major Components / BOM Reference

This is a reproducibility-oriented bill of materials for the major robot concepts represented in the repository. It is not a purchasing quotation and does not claim that every physical component was procured or commissioned.

## Robot design targets

| Item | Target / design basis |
|---|---|
| Degrees of freedom | 6 revolute joints |
| Reach | approximately 1.5 m |
| Payload target | approximately 10 kg |
| Higher design-load checks | approximately 15 kg used in selected sizing/safety calculations |
| Primary structural material | Aluminum 6061-T6 |
| High-stress shaft/pin material considered | 4140 / 42CrMo4 steel |
| Robot status | simulation-validated prototype; physical arm not fully commissioned |

## Final integrated actuator concept

| Joint | Module | Rated torque | Peak/start-stop torque | Rated power | Reduction | Approx. module mass |
|---|---|---:|---:|---:|---:|---:|
| J1 | TD-110-170 | 328 N·m | 702 N·m | 1500 W | 101:1 | 7.61 kg |
| J2 | TD-110-170 | 328 N·m | 702 N·m | 1500 W | 101:1 | 7.61 kg |
| J3 | TD-100-142 | 169 N·m | 411 N·m | 1000 W | 101:1 | 4.46 kg |
| J4 | TD-70-90 | 50 N·m | 102 N·m | 500 W | 101:1 | 1.60 kg |
| J5 | TD-70-90 | 50 N·m | 102 N·m | 500 W | 101:1 | 1.60 kg |
| J6 | TD-70-90 | 50 N·m | 102 N·m | 500 W | 101:1 | 1.60 kg |

The selected modules were intended to simplify the final mechanical integration compared with continuing to develop custom high-ratio reducers for every joint.

## Structural components

| Component | Reference design direction |
|---|---|
| Long links | Hollow cylindrical aluminum shells |
| Later lightweight link section explored | approximately 80 mm OD, 3 mm wall, 74 mm ID |
| Earlier heavier section explored | approximately 110 mm OD, 5 mm wall |
| Internal ribs | explored early, removed from final manufacturing direction |
| Local reinforcement | thicker housings / transitions / bearing and reducer interfaces |
| Joint shafts / pins | high-strength steel concept such as 4140 / 42CrMo4 |
| Fasteners | high-strength metric fasteners sized per final joint design |

Exact wall thickness and local reinforcement should be revalidated against the final actuator packaging and desired stiffness before physical manufacture.

## End effector

The simulated/digital system includes a custom gripper integrated into the robot URDF.

Key requirements for a physical version:

- compatible mounting flange
- sufficient jaw travel for the jig geometry
- position or state feedback if sequence synchronization depends on confirmed closure
- physical grasp force validation
- repeatable TCP calibration

## Control / communication

The selected integrated actuator direction supports industrial communication options including EtherCAT / CAN-class interfaces. The repository currently represents the simulation/control architecture rather than a completed physical fieldbus implementation.

A physical build would additionally require:

- robot controller or industrial PC
- real-time-compatible fieldbus interface
- suitable 24–48 V-class power distribution as required by the selected actuators
- brake control where applicable
- emergency stop / safety architecture
- limit and reference strategy
- wiring, connectors, grounding and shielding

## Simulation software BOM

| Layer | Baseline |
|---|---|
| OS | Ubuntu 22.04 LTS |
| Middleware | ROS 2 Humble |
| Simulation | Gazebo Classic 11 |
| Motion planning | MoveIt 2 |
| Planning pipelines | OMPL + Pilz |
| Visualization | RViz 2 |
| Execution | ros2_control + ros2_controllers |
| GUI | Python 3 + Tkinter |
| Build system | colcon / ament |

## Workcell models

The simulated application also includes:

- harness/placement table
- jig source table
- large jig models
- medium jig models
- small jig models
- target TF frames
- IFRA LinkAttacher-based simulated grasping

## Before purchasing hardware

Re-run or confirm:

1. final link masses and inertias
2. worst-case joint torque including payload and acceleration
3. structural stiffness / TCP deflection
4. actuator thermal duty cycle
5. brake requirements
6. bearing loads
7. shaft/pin stress
8. cable routing and joint rotation limits
9. electrical power budget
10. safety requirements for the actual installation

The actuator table above documents the final project direction, not a substitute for a fresh design review before manufacture.

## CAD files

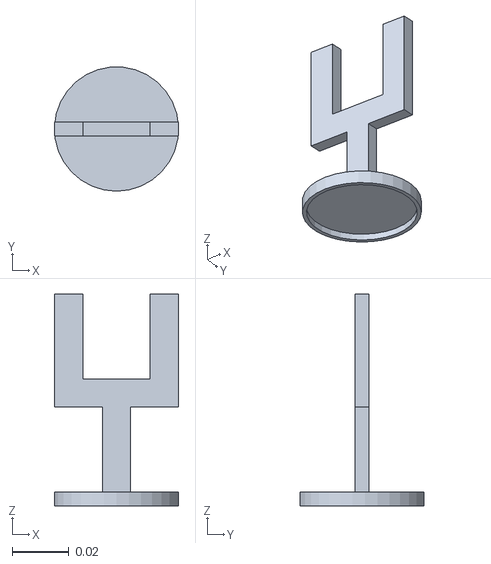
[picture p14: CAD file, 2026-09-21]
src/large_jig_urdf/meshes/large_jig_link.STL
0.0439 x 0.044 x 0.075

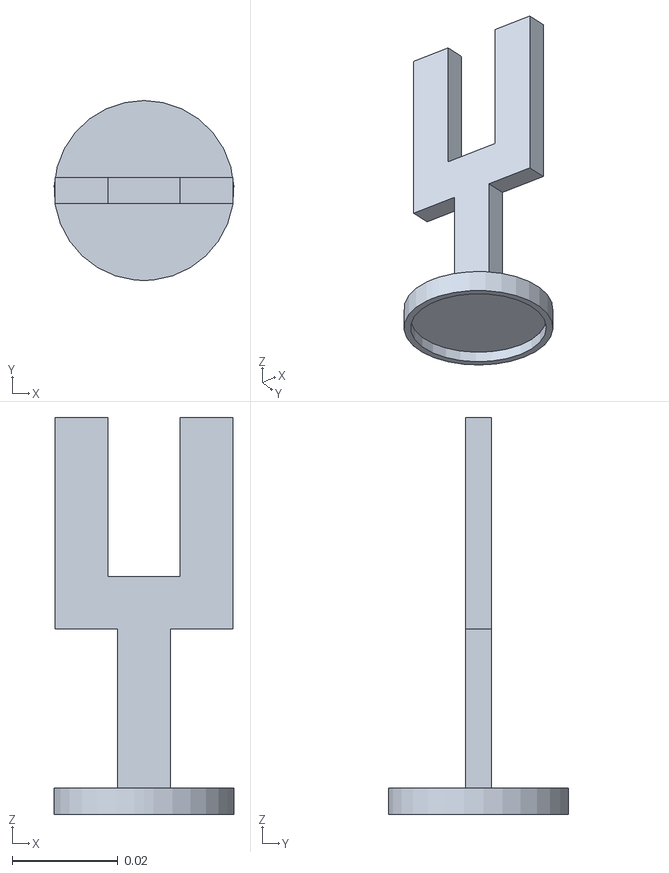
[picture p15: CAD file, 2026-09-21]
src/medium_jig_urdf/meshes/medium_jig_link.STL
0.034 x 0.034 x 0.075

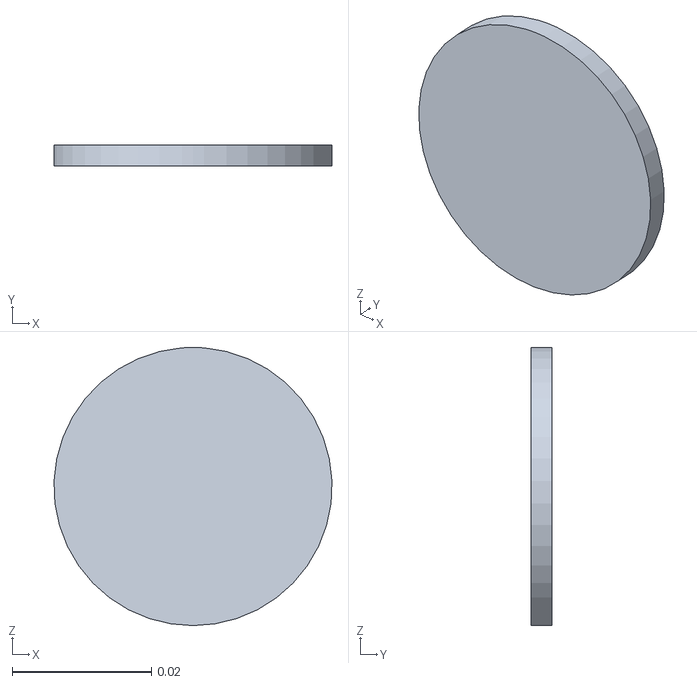
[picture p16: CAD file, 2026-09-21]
src/pick_table_urdf/meshes/l_pick_1_link.STL
0.04 x 0.003 x 0.04

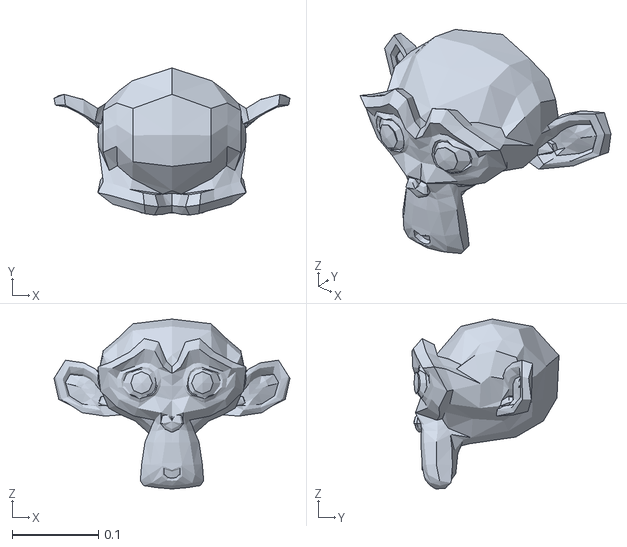
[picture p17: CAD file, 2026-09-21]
src/pymoveit2/examples/assets/suzanne.stl
0.273 x 0.17 x 0.197

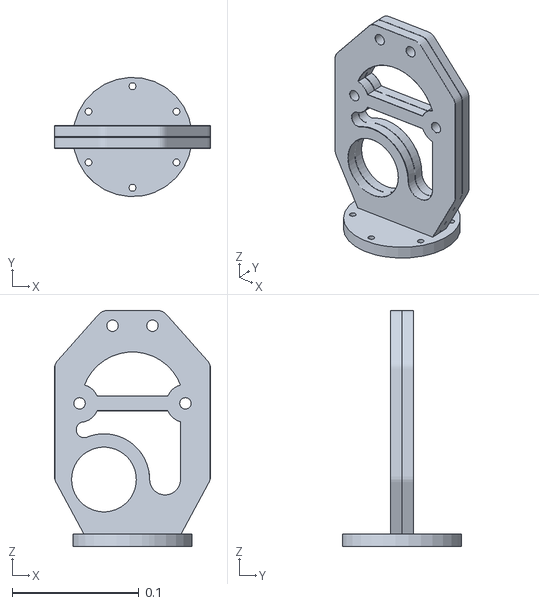
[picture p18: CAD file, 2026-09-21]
src/robot_arm_with_gripper_urdf/meshes/gripper_base.STL
0.123 x 0.0939 x 0.186

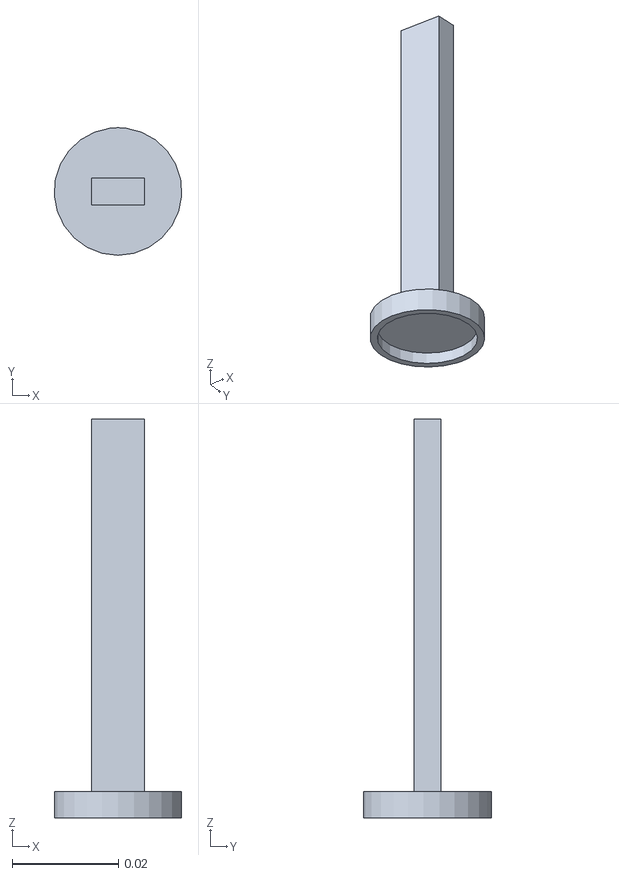
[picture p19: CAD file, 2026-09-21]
src/small_jig_urdf/meshes/small_jig_link.STL
0.024 x 0.024 x 0.075

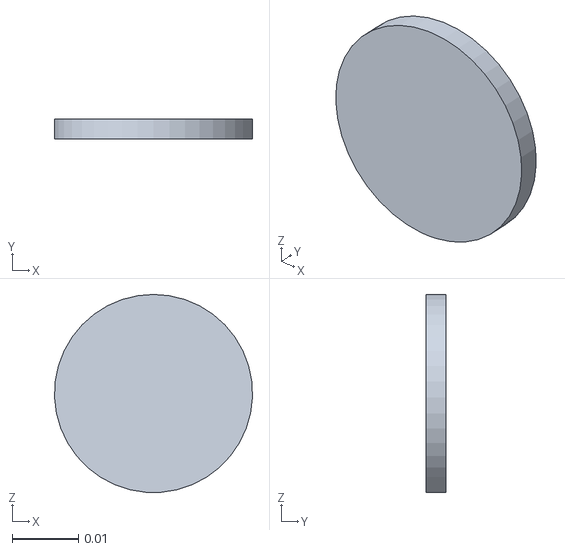
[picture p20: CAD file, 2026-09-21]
src/table_harness_urdf_v3/meshes/m1_target_link.STL
0.03 x 0.003 x 0.03

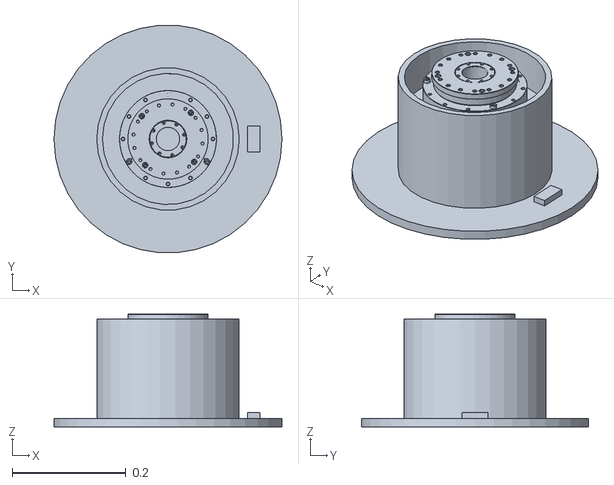
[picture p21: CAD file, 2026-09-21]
src/robot_arm_with_gripper_urdf/meshes/base_link.STL
0.4 x 0.399 x 0.198

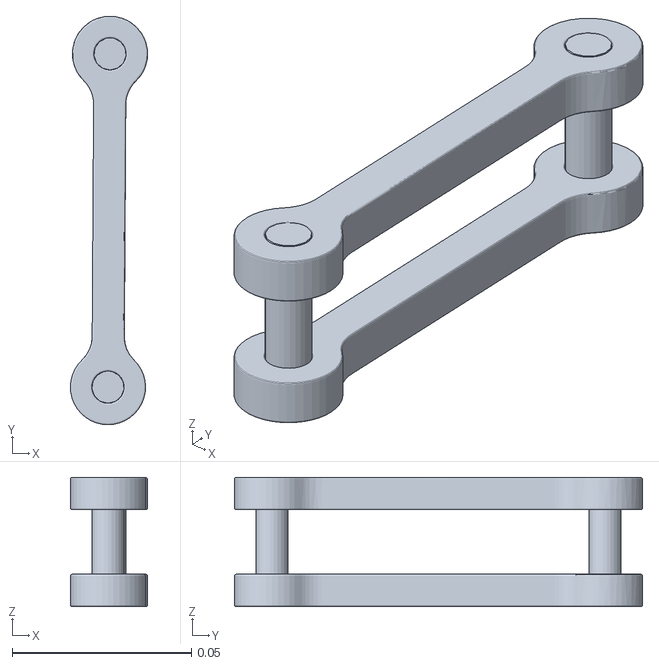
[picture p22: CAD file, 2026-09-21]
src/robot_arm_with_gripper_urdf/meshes/left_linker.STL
0.0216 x 0.114 x 0.036

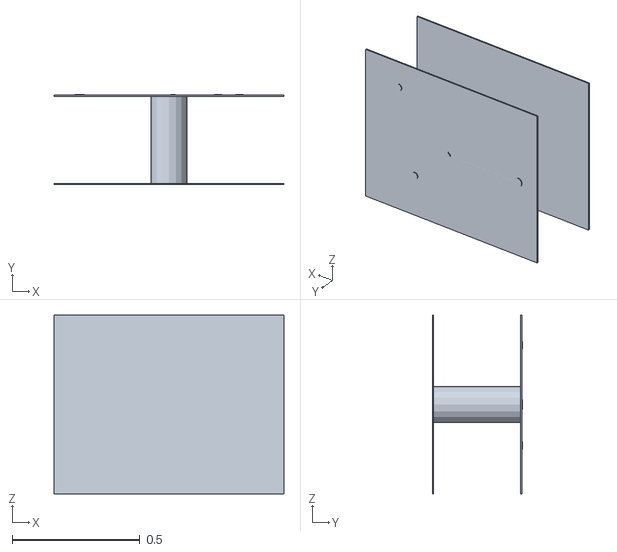
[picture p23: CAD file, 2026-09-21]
src/table_harness_urdf_v3/meshes/table_base_link.STL
0.9 x 0.352 x 0.7

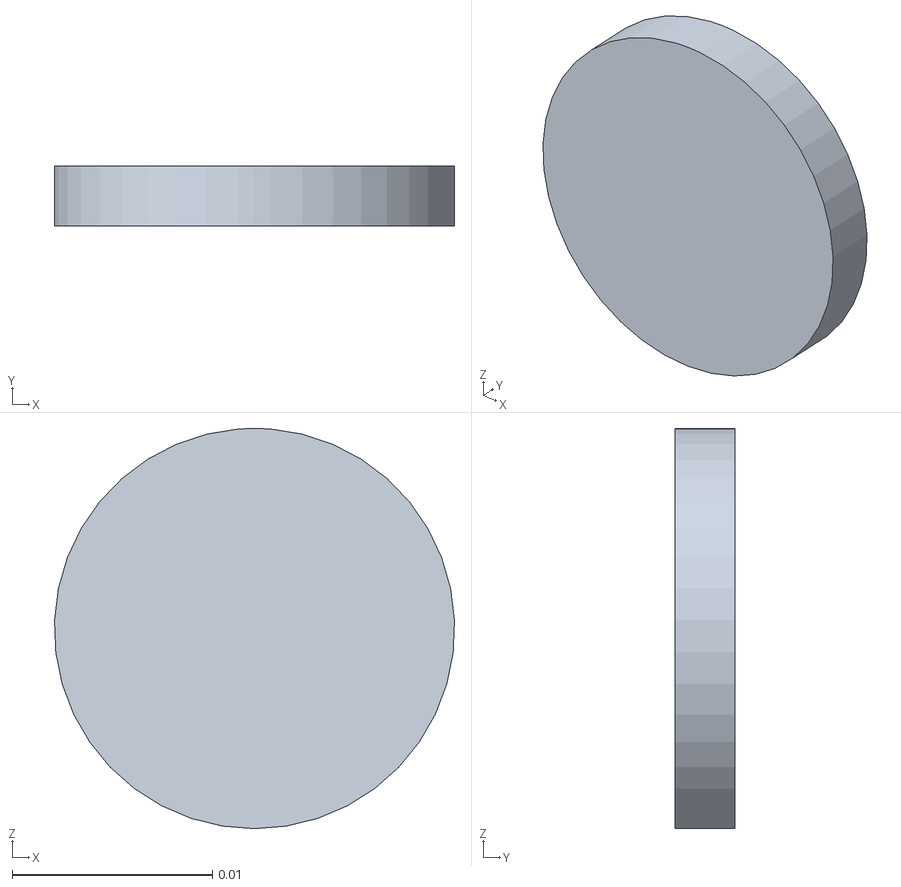
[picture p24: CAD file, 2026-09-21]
src/pick_table_urdf/meshes/s_pick_3_link.STL
0.02 x 0.003 x 0.02

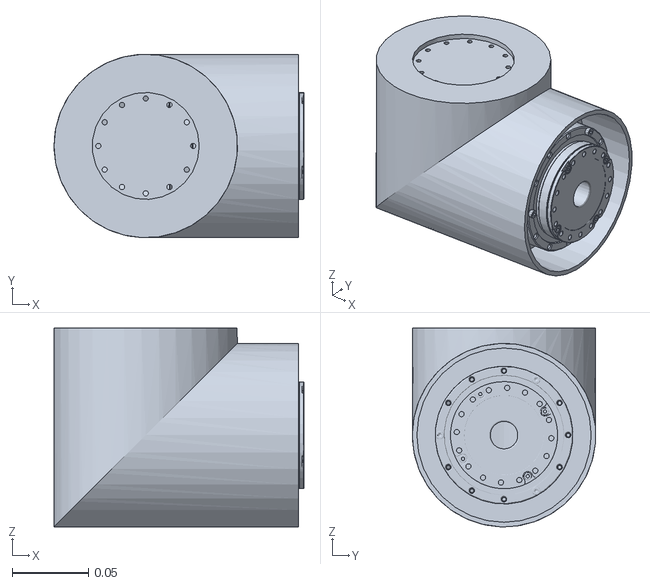
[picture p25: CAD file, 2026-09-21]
src/robot_arm_with_gripper_urdf/meshes/link_5.STL
0.163 x 0.12 x 0.13

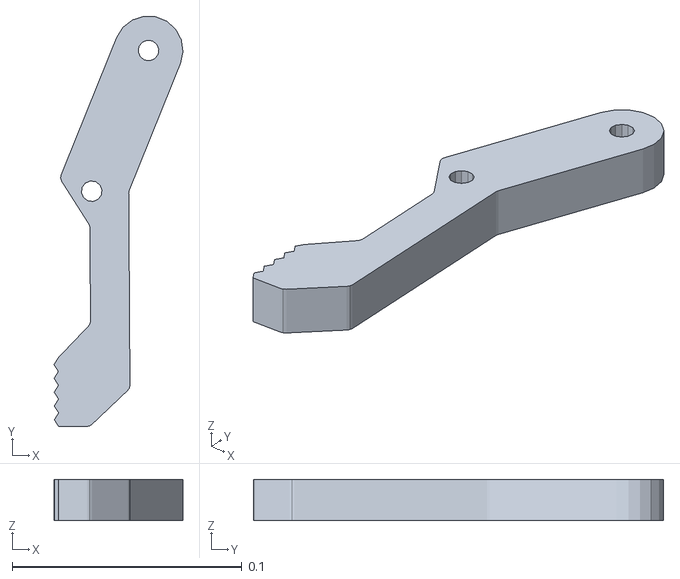
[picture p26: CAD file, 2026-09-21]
src/robot_arm_with_gripper_urdf/meshes/right_jaw.STL
0.0561 x 0.178 x 0.018

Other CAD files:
src/pick_table_urdf/meshes/m_pick_4_link.STL
src/table_harness_urdf_v3/meshes/m2_target_link.STL
src/pick_table_urdf/meshes/m_pick_1_link.STL
src/table_harness_urdf_v3/meshes/l1_target_link.STL
src/pick_table_urdf/meshes/s_pick_4_link.STL
src/pick_table_urdf/meshes/l_pick_2_link.STL
src/pick_table_urdf/meshes/l_pick_3_link.STL
src/pick_table_urdf/meshes/l_pick_4_link.STL
src/pick_table_urdf/meshes/m_pick_2_link.STL
src/pick_table_urdf/meshes/m_pick_3_link.STL
src/pick_table_urdf/meshes/pick_table_base_link.STL
src/pick_table_urdf/meshes/s_pick_1_link.STL
src/pick_table_urdf/meshes/s_pick_2_link.STL
src/robot_arm_with_gripper_urdf/meshes/left_gear.STL
src/robot_arm_with_gripper_urdf/meshes/left_jaw.STL
src/robot_arm_with_gripper_urdf/meshes/link_1.STL
src/robot_arm_with_gripper_urdf/meshes/link_2.STL
src/robot_arm_with_gripper_urdf/meshes/link_3.STL
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

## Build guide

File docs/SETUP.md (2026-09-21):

# Setup Guide

This project was developed and validated with the following baseline:

```text
Ubuntu 22.04 LTS
ROS 2 Humble
Gazebo Classic 11
MoveIt 2
RViz 2
ros2_control
ros2_controllers
OMPL
Pilz Industrial Motion Planner
Python 3 / Tkinter
colcon / ament
```

## 1. Install ROS 2 Humble

Follow the official ROS 2 Humble Ubuntu installation instructions, then install the desktop package:

```bash
sudo apt update
sudo apt install -y ros-humble-desktop
```

Source ROS:

```bash
source /opt/ros/humble/setup.bash
```

## 2. Install development tools

```bash
sudo apt install -y \
  build-essential \
  cmake \
  git \
  python3-pip \
  python3-tk \
  python3-yaml \
  python3-rosdep \
  python3-colcon-common-extensions \
  python3-vcstool
```

Initialize rosdep if needed:

```bash
sudo rosdep init
rosdep update
```

## 3. Install control and simulation packages

```bash
sudo apt install -y \
  ros-humble-ros2-control \
  ros-humble-ros2-controllers \
  gazebo \
  ros-humble-gazebo-ros-pkgs \
  ros-humble-gazebo-ros2-control
```

## 4. Install MoveIt 2

```bash
sudo apt install -y \
  ros-humble-moveit \
  ros-humble-moveit-planners-ompl \
  ros-humble-pilz-industrial-motion-planner
```

## 5. Clone the repository

The repository itself is the colcon workspace and already contains a `src/` directory:

```bash
cd ~
git clone https://github.com/Yousef-Elbeltagy/6DOF-Robot-Arm-ROS2.git robot_arm_ws
cd ~/robot_arm_ws
```

Expected layout:

```text
~/robot_arm_ws/
├── src/
├── scripts/
├── config/
├── docs/
└── README.md
```

Do not clone the complete repository into `~/robot_arm_ws/src`.

## 6. Install package dependencies

Recommended:

```bash
cd ~/robot_arm_ws
bash scripts/setup_dependencies.sh
```

Or manually:

```bash
source /opt/ros/humble/setup.bash
cd ~/robot_arm_ws
rosdep install --from-paths src --ignore-src -r -y --rosdistro humble
```

## 7. Build

Recommended:

```bash
cd ~/robot_arm_ws
bash scripts/build_workspace.sh
```

Or manually:

```bash
cd ~/robot_arm_ws
source /opt/ros/humble/setup.bash
colcon build --symlink-install
source ~/robot_arm_ws/install/setup.bash
```

## 8. Restore GUI configuration

```bash
cp ~/robot_arm_ws/config/robot_arm_saved_poses.json ~/robot_arm_saved_poses.json
cp ~/robot_arm_ws/config/robot_arm_tcp_config.json ~/robot_arm_tcp_config.json
```

## 9. Verify the environment

```bash
cd ~/robot_arm_ws
bash scripts/check_system.sh
```

The public repository was validated on the development machine with all environment checks passing.

## 10. Run the project

```bash
cd ~/robot_arm_ws
bash scripts/start_robot.sh
```

The launcher starts Gazebo Classic, waits for the arm and gripper controllers, starts MoveIt, opens RViz, and launches the custom Tkinter GUI.

The public repository was build-tested and launch-tested after publication.

## 11. Main project components

Important packages include:

```text
robot_arm_with_gripper_urdf
robot_arm_moveit_config
robot_arm_python
pymoveit2
table_harness_urdf_v3
pick_table_urdf
large_jig_urdf
medium_jig_urdf
small_jig_urdf
IFRA_LinkAttacher
```

## 12. Useful checks

Controllers:

```bash
ros2 control list_controllers
```

MoveIt sequence action:

```bash
ros2 action info /sequence_move_group
```

Gripper transform:

```bash
timeout 3 ros2 run tf2_ros tf2_echo link_6 gripper_base
```

## Notes

- The project was developed on Gazebo Classic 11 rather than modern Gz Sim.
- The simulated jig attach/detach system uses a modified IFRA LinkAttacher implementation.
- `warehouse_ros_mongo` is not required for the supported planning/simulation workflow.
- Native SolidWorks and neutral STEP CAD packages are available under `cad/`.
- The robot is a development/simulation project and not a certified industrial safety system.

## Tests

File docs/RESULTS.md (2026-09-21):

# Results & Demonstrated Capabilities

This page summarizes what the project actually demonstrated by the end of the development period.

## Mechanical / CAD

- Complete 6-DOF articulated robot concept developed in SolidWorks.
- Joint axes and reference coordinate systems prepared for URDF export.
- Main link material selected as 6061-T6 aluminum.
- Structural stress and displacement studies completed.
- Dynamic joint torque model completed.
- Final integrated joint-module concept selected.
- Gripper CAD integrated into the full robot model.

## Digital robot model

- Robot exported into a ROS-compatible URDF structure.
- Six arm joints represented in the digital kinematic chain.
- Gripper hierarchy integrated into the same robot model.
- Link mass, inertia, visual mesh and collision mesh carried into simulation.

## ROS 2 / simulation

- Robot launched successfully in ROS 2 Humble.
- Complete robot and gripper loaded in Gazebo Classic 11.
- ros2_control controllers activated for arm and gripper.
- MoveIt 2 configured for the six-axis arm.
- RViz used to verify robot state, planning scene and target poses.
- OMPL and Pilz planning pipelines used during development.

## Operator interface

The custom Python/Tkinter controller supports:

- Cartesian jogging
- joint jogging
- speed override
- WORLD / FLANGE / TOOL jog frames
- configurable TCP
- saved poses
- exact joint-zero HOME
- sequence programming
- STOP / CONTINUE waypoint behavior
- blend radius
- PTP / LIN selection
- digital inputs and outputs
- gripper commands

## Autonomous workcell

The automatic jig-placement workflow demonstrated:

- dynamic TF-based target discovery
- free-target filtering
- jig-type inference from target naming
- virtual scan for matching jig models
- used-jig inventory tracking
- runtime IK
- closest IK branch selection
- simulated attach/detach
- placement validation
- occupied-target tracking
- single-target automatic placement
- complete-table automatic execution
- immediate STOP / RESUME

## Important reliability improvements

Several problems were solved during development rather than hidden from the final system:

- duplicate MoveIt process conflicts
- stale TCP pose during jig acquisition
- gripper-result timeout under slow Gazebo real-time factor
- undesirable IK wrist branches
- reuse of already-placed jigs
- collision risk from low inter-target travel height
- Gazebo native crash during detach
- STOP behavior that initially waited too long

## Project status

The strongest final claim is:

> **Simulation-validated 6-DOF robot and automatic jig-placement application with a custom ROS 2 operator interface.**

The project is not presented as a physically commissioned or safety-certified production robot. Physical actuator integration, calibration, industrial safety and final cell commissioning remain future work.

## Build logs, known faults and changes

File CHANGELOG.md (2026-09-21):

# Changelog

This changelog records the major public milestones of the 6DOF Robot Arm ROS 2 project.

## 2026-09 — Public simulation baseline

### Added

- complete ROS 2 Humble workspace for the six-axis robot and gripper,
- Gazebo Classic workcell simulation,
- MoveIt 2 planning and RViz integration,
- ros2_control arm and gripper execution,
- custom Python/Tkinter operator interface,
- saved-pose and TCP configuration,
- industrial-style Sequence Controller with PTP/LIN selection, blending, I/O logic, gripper actions, STOP/RESUME, and waypoint behavior,
- runtime multi-seed IK and wrist-aware branch selection,
- automatic jig selection, pickup, transfer, placement, validation, inventory tracking, and full-table execution,
- stable Gazebo link-detach handling using update-thread deferred detach,
- native SolidWorks CAD archives for the robot, gripper, jigs, and workcell,
- neutral STEP exports for the complete workcell and its components,
- project setup, reproduction, continuation, troubleshooting, BOM, architecture, and engineering documentation,
- repository quality checks for Python syntax, shell syntax, package manifests, required project files, and generated-artifact leakage,
- helper scripts for dependency installation, workspace builds, environment verification, and complete startup.

### Validated

- public repository built successfully from its own `src/` tree on Ubuntu 22.04 / ROS 2 Humble,
- environment check completed with all reported checks passing on the development machine,
- Gazebo, MoveIt, RViz, the robot GUI, robot model, arm controller, and gripper controller launched successfully from the public repository.

### Documentation cleanup

- corrected the public workspace layout so the repository is cloned directly as `~/robot_arm_ws`,
- removed the unavailable optional `warehouse_ros_mongo` dependency from the supported workflow,
- documented both native SolidWorks and STEP CAD packages,
- aligned setup and reproduction instructions with the validated public build and launch process.

## Project status

The current public baseline is a **simulation-validated engineering prototype**. The physical six-axis arm was not fully commissioned during the project period because the selected integrated actuator modules had a long procurement lead time.

Future hardware work includes physical actuator integration, EtherCAT/CAN communication, robot calibration, camera-based target recognition, workplane calibration, machine-safety engineering, and complete cell commissioning.

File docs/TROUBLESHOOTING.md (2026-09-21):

# Troubleshooting

Use this guide before changing coordinates, controller names, IK logic, timeouts, or workcell geometry. Many failures in this project were caused by process duplication, stale state, asynchronous execution, or simulator-thread timing rather than by the target pose itself.

## 1. More than one MoveIt process

Check:

```bash
ros2 node list | grep move_group
```

There should normally be one `/move_group` node.

Symptoms of duplicate MoveIt instances can include:

- confusing action behavior
- goals accepted by the wrong process
- inconsistent planning state
- sequence actions failing while the robot still moves

Stop duplicate launch processes before changing planning code.

## 2. Small motions work but larger plans fail

Check:

- current robot state is valid
- joint limits
- collision scene
- start state freshness
- planning pipeline
- requested orientation

Try a very small Cartesian or joint change first. If that works, increase motion gradually rather than immediately changing URDF geometry or controller settings.

## 3. LIN motion fails

PTP became the most thoroughly validated sequence mode. LIN through Pilz is more sensitive to:

- start-state validity
- IK feasibility
- acceleration constraints
- joint-state freshness
- Cartesian path geometry

Confirm PTP works first. Then isolate one LIN segment and test it independently.

## 4. Sequence says failed although motion occurred

Inspect both the MoveIt sequence action and the underlying trajectory-controller result.

Relevant interfaces:

```text
/sequence_move_group
/arm_controller/follow_joint_trajectory
```

Do not assume that goal acceptance means successful completion.

## 5. Gripper command overlaps the next arm move

The known-good sequence architecture uses a gripper barrier:

```text
arm segment
   ↓
stop
   ↓
send gripper goal
   ↓
wait for FollowJointTrajectory result
   ↓
continue arm motion
```

If the arm moves before the gripper finishes, check that the generic output handler is not also issuing the gripper command and that execution waits for the real action result.

## 6. STOP does not stop motion immediately

The intended STOP path cancels both:

```text
active MoveIt goal
active arm-controller FollowJointTrajectory goal
```

A software flag alone is not sufficient.

Verify action cancellation before changing GUI state logic.

## 7. Automatic placement cannot find a target

Inspect available TF frames:

```bash
ros2 run tf2_tools view_frames
```

or inspect TF output manually.

Automatic target discovery expects frame names ending in:

```text
_target_link
```

Also verify that the target has not already been added to `filled_placement_targets`.

## 8. Wrong jig selected

The system must exclude jig models already recorded in:

```python
placed_jig_models
```

If a jig already placed on the board becomes the nearest jig during a later scan, verify used-jig filtering before changing source-table coordinates.

## 9. "Gripper closed but no jig was acquired"

Possible causes include:

- stale GUI TCP pose
- selected jig is outside pickup range
- attach service unavailable
- unexpected model/link name
- attach service returned failure

The GUI should refresh its pose before nearest-jig selection rather than relying on old cached coordinates.

Useful checks:

```bash
ros2 service list | grep attach
```

and inspect runtime logs for attach-distance diagnostics.

Do not immediately enlarge pickup thresholds or change jig coordinates without first checking the reported TCP/jig distance.

## 10. Gazebo crashes during jig release

A critical historical issue was a native `gzserver` crash caused by calling `Joint::Detach()` directly from a ROS service callback thread.

Known-good behavior:

```text
ROS service callback
    ↓
queue detach request
    ↓
Gazebo OnUpdate()
    ↓
Joint::Detach()
```

If detach crashes return, verify this modified threading behavior is still present in `src/IFRA_LinkAttacher/`.

Do not replace the package with an upstream copy without preserving the fix.

## 11. Gazebo is running but windows are not visible

Check running processes:

```bash
ps aux | grep -E 'gzserver|gzclient|rviz2|move_group'
```

A process can be alive even when its window is hidden, off-screen, or attached to another workspace.

Use the diagnostic launcher if needed:

```bash
bash scripts/start_robot_DIAGNOSTIC_GAZEBO.sh
```

## 12. Controllers are not active

Check:

```bash
ros2 control list_controllers
```

Expected trajectory controllers should be active before starting the GUI.

Also inspect available actions:

```bash
ros2 action list
```

You should see arm and gripper `FollowJointTrajectory` actions.

## 13. GUI starts but poses/TCP are missing

The GUI expects:

```text
~/robot_arm_saved_poses.json
~/robot_arm_tcp_config.json
```

Restore the repository copies:

```bash
cp config/robot_arm_saved_poses.json ~/robot_arm_saved_poses.json
cp config/robot_arm_tcp_config.json ~/robot_arm_tcp_config.json
```

## 14. Wrist flips during automatic placement

A valid IK solution is not necessarily a good motion.

The current automatic controller intentionally:

1. tries multiple IK seeds
2. collects valid solutions
3. computes wrapped joint deltas
4. weights wrist movement more strongly
5. selects the lowest-motion candidate

Before adding a target-specific joint override, inspect candidate selection and confirm the current joint state is fresh.

## 15. Robot moves but TCP is wrong

Do not confuse:

```text
link_6 -> gripper_base
```

with the configured tool-center-point offset.

The validated TCP Z translation is approximately:

```text
0.4193463143 m
```

Check `~/robot_arm_tcp_config.json`.

## 16. Full-table run reuses a target or jig

Both state trackers are required:

```python
placed_jig_models
filled_placement_targets
```

They solve different problems and must remain independent.

## 17. Build fails after editing packages

Clean only when necessary:

```bash
cd ~/robot_arm_ws
rm -rf build install log
source /opt/ros/humble/setup.bash
colcon build --symlink-install
```

Then source again:

```bash
source ~/robot_arm_ws/install/setup.bash
```

## 18. First debugging principle

When a previously working behavior breaks:

1. reproduce once
2. capture the exact error/output
3. verify process state
4. verify controller/action/service availability
5. inspect current robot/TCP state
6. change one thing only
7. re-test

Avoid simultaneous changes to motion planning, coordinates, timeouts, and simulator logic. That makes regressions much harder to isolate.

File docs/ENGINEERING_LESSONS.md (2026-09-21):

# Engineering Lessons from the Project

This project was valuable not because every idea worked immediately, but because it required mechanical, simulation and software problems to be solved across several layers of a robotics stack.

## 1. Robot design is a system problem

A payload number by itself is not enough to size a robot joint. The joint must also carry downstream links, actuators, wrist components, gripper mass and dynamic loading.

That is why J2 became the governing axis even though a simple payload-only gravity calculation looked much smaller than the final dynamic torque requirement.

## 2. Strength is not the same as stiffness

One FEA study could look acceptable from a yield-stress perspective while the TCP deflection was still too large.

For a long robotic arm, stiffness matters directly to positioning accuracy. The project therefore had to evaluate both stress and displacement rather than treating factor of safety as the only structural metric.

## 3. Local stress concentrations need geometric fixes

Very high stress at a sharp housing transition did not mean the entire link was overloaded. Probe results showed stress falling rapidly away from the transition.

The useful response was not simply to make every tube thicker. Better fixes were larger fillets, smoother geometry and better local load paths.

## 4. A custom gearbox can become a project by itself

The custom cycloidal reducer work was technically interesting, but it also demonstrated how quickly precision gearbox development can consume a schedule.

Interference, bearing stiffness, heat treatment, surface finish, backlash and manufacturing tolerances all matter. Moving to integrated joint modules reduced risk and allowed the project to focus on the complete robot system.

## 5. CAD coordinate systems matter later

Joint axes and coordinate frames defined in SolidWorks directly affected URDF behavior, MoveIt kinematics and Gazebo motion.

Good coordinate-system discipline early in the CAD model saved large amounts of debugging later.

## 6. Simulation failures can come from different layers

A motion failure could originate from:

- GUI state
- stale pose data
- TF
- IK branch selection
- MoveIt planning
- trajectory timing
- ros2_control
- Gazebo physics
- plugin threading

The only reliable way to debug the system was to identify which layer actually failed before changing parameters.

## 7. Stale GUI state can cause real control logic bugs

The jig-acquisition logic initially used a periodically refreshed TCP pose. Immediately after a descent, the cached pose could still describe the higher approach point, making the robot appear too far from the jig.

The fix was to read the live pose synchronously at the moment the pickup-distance decision was made.

## 8. Simulation time and wall-clock time are not the same

Gazebo sometimes ran with a real-time factor well below 1.0. A simulated trajectory that looked short could take considerably longer in wall-clock time.

This explained gripper-controller results that arrived after the GUI's original timeout even though the controller itself had executed correctly.

## 9. Valid IK is not always good IK

The first mathematically valid IK solution is not necessarily the best motion for a real robot.

The project encountered solutions with large wrist rotations. Evaluating several seeds and choosing the branch closest to the current joint configuration produced much more natural motion without introducing target-specific hacks.

## 10. Track state explicitly in autonomous routines

The automatic system needed two different state sets:

- which physical jig models had already been used
- which target locations had already been filled

Without both, a full-table routine could reuse a placed jig or revisit an occupied target.

## 11. Threading matters in simulator plugins

The most severe Gazebo stability problem was a native `gzserver` crash during link detach.

The important lesson was that changing Gazebo physics/joint state from a ROS callback thread can be unsafe. Queuing the request and executing `Joint::Detach()` from Gazebo's own update thread stabilized the behavior.

## 12. STOP should mean STOP

An operator-facing STOP control is not useful if it only prevents the next command while allowing the current long trajectory to complete.

The final automatic-stop behavior cancels both the MoveIt-level goal and the active controller trajectory so the robot can interrupt motion during the current step.

## 13. Preserve known-good checkpoints

As the GUI accumulated manual jogging, TCP logic, sequences, I/O, gripper control and autonomous placement, large refactors became risky.

Dated checkpoints made it possible to compare regressions without losing newer features.

## 14. Build the simplest version that proves the architecture

The physical robot was not completed within the project timeframe, but the project still validated a substantial architecture:

- CAD-to-URDF
- planning
- simulation
- control
- GUI
- gripper
- autonomous workcell logic

That creates a much stronger basis for future hardware integration than starting directly with unvalidated hardware and software at the same time.

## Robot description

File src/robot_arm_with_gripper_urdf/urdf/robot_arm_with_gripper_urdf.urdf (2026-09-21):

<robot name="robot_arm">
    <link name="world"/>

  <joint name="world_to_base" type="fixed">
    <parent link="world"/>
    <child link="base_link"/>
    <origin xyz="0 0 0" rpy="0 0 0"/>
  </joint>

  <link name="base_link">
    <inertial>
      <origin xyz="0.00033791 -8.6322E-06 0.072151" rpy="0 0 0" />
      <mass value="4.4055" />
      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
    </inertial>
    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
  </link>
  <link name="link_1">
    <inertial>
      <origin xyz="0.0629481179134198 2.38289723024472E-05 0.133600984061708" rpy="0 0 0" />
      <mass value="1.87651195817962" />
      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
    </inertial>
    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
  </link>
  <joint name="joint_1" type="revolute">
    <origin xyz="0 0 0.189" rpy="0 0 1.5708" />
    <parent link="base_link" />
    <child link="link_1" />
    <axis xyz="0 0 1" />
    <limit lower="-3.1416" upper="3.1416" effort="300" velocity="3.1416" />
  </joint>
  <link name="link_2">
    <inertial>
      <origin xyz="2.02803890482726E-05 0.393390159127154 0.0869587267477594" rpy="0 0 0" />
      <mass value="1.94569960752305" />
      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
    </inertial>
    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
  </link>
  <joint name="joint_2" type="revolute">
    <origin xyz="0.16 0 0.143" rpy="1.5708 0 1.5708" />
    <parent link="link_1" />
    <child link="link_2" />
    <axis xyz="0 0 1" />
    <limit lower="-1.5708" upper="3.1416" effort="500" velocity="3.1416" />
  </joint>
  <link name="link_3">
    <inertial>
      <origin xyz="-0.24100644770776 -1.78769323841976E-05 -0.0842683130518023" rpy="0 0 0" />
      <mass value="0.992123718214445" />
      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
    </inertial>
    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
  </link>
  <joint name="joint_3" type="revolute">
    <origin xyz="0 0.65 0.01" rpy="0 0 0" />
    <parent link="link_2" />
    <child link="link_3" />
    <axis xyz="0 0 -1" />
    <limit lower="-2.3562" upper="2.3562" effort="350" velocity="3.1416" />
  </joint>
  <link name="link_4">
    <inertial>
      <origin xyz="0.0124721068231639 -6.80014488052549E-08 0.0730062206573129" rpy="0 0 0" />
      <mass value="0.288479921044316" />
      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
    </inertial>
    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
  </link>
  <joint name="joint_4" type="revolute">
    <origin xyz="-0.6 0 -0.09" rpy="0 -1.5708 0" />
    <parent link="link_3" />
    <child link="link_4" />
    <axis xyz="0 0 -1" />
    <limit lower="-3.1416" upper="3.1416" effort="120" velocity="3.1416" />
  </joint>
  <link name="link_5">
    <inertial>
      <origin xyz="0.0140876410223744 7.23890825060636E-08 -0.0567094508970235" rpy="0 0 0" />
      <mass value="0.255398508666998" />
      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
    </inertial>
    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
  </link>
  <joint name="joint_5" type="revolute">
    <origin xyz="0.0999999999999999 0 0.0998500000000002" rpy="0 -1.5707963267949 0" />
    <parent link="link_4" />
    <child link="link_5" />
    <axis xyz="0 0 -1" />
    <limit lower="-2.0944" upper="2.0944" effort="120" velocity="3.1416" />
  </joint>
  <link name="link_6">
    <inertial>
      <origin xyz="1.59432845175944E-07 -9.56734994561614E-08 0.0348586525989366" rpy="0 0 0" />
      <mass value="0.648640309376528" />
      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
    </inertial>
    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
  </link>
  <joint name="joint_6" type="revolute">
    <origin xyz="0.1 0 -0.06985" rpy="0 1.5708 0" />
    <parent link="link_5" />
    <child link="link_6" />
    <axis xyz="0 0 -1" />
    <limit lower="-3.1416" upper="3.1416" effort="50" velocity="3.1416" />
  </joint>
  <link name="gripper_base">
    <inertial>
      <origin xyz="0.0012153 -1.654E-09 0.076285" rpy="0 0 0" />
      <mass value="0.28531" />
      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
    </inertial>
    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
  </link>
  <joint name="gripper_mount_joint" type="fixed">
    <origin xyz="0 0 0.04985" rpy="0 0 0" />
    <parent link="link_6" />
    <child link="gripper_base" />
    <axis xyz="0 0 0" />
  </joint>
  <link name="left_gear">
    <inertial>
      <origin xyz="0.00016205 -0.021316 0.0089676" rpy="0 0 0" />
      <mass value="0.076333" />
      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
    </inertial>
    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
  </link>
  <joint name="left_gear_joint" type="revolute">
    <origin xyz="-0.0417 -0.00015974 0.1128" rpy="-1.5708 0 0" />
    <parent link="gripper_base" />
    <child link="left_gear" />
    <axis xyz="0 0 -1" />
    <limit lower="0" upper="1.76" effort="100" velocity="3" />
  </joint>
  <link name="left_jaw">
    <inertial>
      <origin xyz="0.015718 -0.070491 1.4877E-14" rpy="0 0 0" />
      <mass value="0.079323" />
      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
    </inertial>
    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
  </link>
  <joint name="left_jaw_joint" type="revolute">
    <origin xyz="0.00070701 -0.092997 0.00015974" rpy="0 0 0" />
    <parent link="left_gear" />
    <child link="left_jaw" />
    <axis xyz="0 0 -1" />
    <limit lower="-1.76" upper="0" effort="100" velocity="3" />
    <mimic joint="left_gear_joint" multiplier="-1" offset="0" />
  </joint>
  <link name="right_gear">
    <inertial>
      <origin xyz="-0.00016176 -0.021277 0.0089569" rpy="0 0 0" />
      <mass value="0.076159" />
      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
    </inertial>
    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
  </link>
  <joint name="right_gear_joint" type="revolute">
    <origin xyz="0.0417 -0.00015974 0.1128" rpy="-1.5708 0 0" />
    <parent link="gripper_base" />
    <child link="right_gear" />
    <axis xyz="0 0 -1" />
    <limit lower="-1.76" upper="0" effort="100" velocity="3" />
    <mimic joint="left_gear_joint" multiplier="-1" offset="0" />
  </joint>
  <link name="right_jaw">
    <inertial>
      <origin xyz="-0.0157181141759559 -0.0704910320406826 1.49880108324396E-14" rpy="0 0 0" />
      <mass value="0.0793226646010456" />
      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
    </inertial>
    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
  </link>
  <joint name="right_jaw_joint" type="revolute">
    <origin xyz="-0.00070701 -0.092997 0.00015974" rpy="0 0 0" />
    <parent link="right_gear" />
    <child link="right_jaw" />
    <axis xyz="0 0 1" />
    <limit lower="-1.76" upper="0" effort="100" velocity="3" />
    <mimic joint="left_gear_joint" multiplier="-1" offset="0" />
  </joint>
  <link name="left_linker">
    <inertial>
      <origin xyz="-0.00028424 -0.046499 0.00015974" rpy="0 0 0" />
      <mass value="0.026664" />
      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
    </inertial>
    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
  </link>
  <joint name="left_linker_joint" type="revolute">
    <origin xyz="-0.015719 -0.00015974 0.174" rpy="-1.5708 0 0" />
    <parent link="gripper_base" />
    <child link="left_linker" />
    <axis xyz="0 0 -1" />
    <limit lower="0" upper="1.76" effort="100" velocity="3" />
    <mimic joint="left_gear_joint" multiplier="1" offset="0" />
  </joint>
  <link name="right_linker">
    <inertial>
      <origin xyz="0.00028424 -0.046499 0.00015974" rpy="0 0 0" />
      <mass value="0.026664" />
      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
    </inertial>
    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
  </link>
  <joint name="right_linker_joint" type="revolute">
    <origin xyz="0.015719 -0.00015974 0.174" rpy="-1.5708 0 0" />
    <parent link="gripper_base" />
    <child link="right_linker" />
    <axis xyz="0 0 -1" />
    <limit lower="-1.76" upper="0" effort="100" velocity="3" />
    <mimic joint="left_gear_joint" multiplier="-1" offset="0" />
  </joint>
  <ros2_control name="GazeboSystem" type="system">
    <hardware>
      <plugin>gazebo_ros2_control/GazeboSystem</plugin>
    </hardware>

    <joint name="joint_1">
      <command_interface name="position"/>
      <state_interface name="position">
        <param name="initial_value">0.0</param>
      </state_interface>
      <state_interface name="velocity"/>
    </joint>

    <joint name="joint_2">
      <command_interface name="position"/>
      <state_interface name="position">
        <param name="initial_value">0.0</param>
      </state_interface>
      <state_interface name="velocity"/>
    </joint>

    <joint name="joint_3">
      <command_interface name="position"/>
      <state_interface name="position">
        <param name="initial_value">0.0</param>
      </state_interface>
      <state_interface name="velocity"/>
    </joint>

    <joint name="joint_4">
      <command_interface name="position"/>
      <state_interface name="position">
        <param name="initial_value">0.0</param>
      </state_interface>
      <state_interface name="velocity"/>
    </joint>
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

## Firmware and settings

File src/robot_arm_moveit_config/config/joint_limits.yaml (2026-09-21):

# joint_limits.yaml allows the dynamics properties specified in the URDF to be overwritten or augmented as needed

default_velocity_scaling_factor: 0.1
default_acceleration_scaling_factor: 0.1

joint_limits:
  joint_1:
    has_velocity_limits: true
    max_velocity: 3.1415999999999999
    has_acceleration_limits: true
    max_acceleration: 1.0
  joint_2:
    has_velocity_limits: true
    max_velocity: 3.1415999999999999
    has_acceleration_limits: true
    max_acceleration: 1.0
  joint_3:
    has_velocity_limits: true
    max_velocity: 3.1415999999999999
    has_acceleration_limits: true
    max_acceleration: 1.0
  joint_4:
    has_velocity_limits: true
    max_velocity: 3.1415999999999999
    has_acceleration_limits: true
    max_acceleration: 1.0
  joint_5:
    has_velocity_limits: true
    max_velocity: 3.1415999999999999
    has_acceleration_limits: true
    max_acceleration: 1.0
  joint_6:
    has_velocity_limits: true
    max_velocity: 3.1415999999999999
    has_acceleration_limits: true
    max_acceleration: 1.0
  left_gear_joint:
    has_velocity_limits: true
    max_velocity: 3.0
    has_acceleration_limits: true
    max_acceleration: 1.0

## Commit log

2026-09-21 Add complete ROS 2 robot arm simulation and control system
    [base_link.STL, controllers.yaml, gripper_base.STL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]
2026-09-21 Add real CAD, simulation and GUI project screenshots
2026-09-21 Expand project gallery with real CAD simulation and GUI screenshots
2026-09-21 Add SolidWorks CAD model archives
2026-09-21 Expand Sequence documentation with current GUI captures
2026-09-21 Refresh gallery with current Gazebo and Sequence screenshots
2026-09-21 Add mechanical design section and CAD images
2026-09-21 Add major component and actuator BOM reference
2026-09-21 Document SolidWorks CAD model archives
2026-09-21 Document STEP CAD exports
2026-09-21 Allow published CAD archives while ignoring other large packages
2026-09-21 Expand documentation index with CAD and project-status links
2026-09-21 Polish README with validated setup, CAD sources, CI, and project navigation
